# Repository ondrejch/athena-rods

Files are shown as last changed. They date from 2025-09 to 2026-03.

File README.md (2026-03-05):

# ATHENA-rods
Automated Teaching Hardware for Explaining Nuclear Absorption Rod(s)

ATHENA-rods is a hands-on teaching platform built around two Raspberry Pi 5 units and a small visualization app. It demonstrates how a reactor’s neutron population responds to control-rod motion using a real-time Point Kinetics Equation (PKE) simulation, live sensors, actuators, and simple displays.

- Instrument Box (RPi5): motor + servo moving a physical “control rod,” ultrasonic distance sensor, limit switch, and an 8×8 MAX7219 LED matrix. 
It also calibrates the ultrasonic ranging by adjusting the speed of sound using temperature and humidity from a DHT11 sensor.
- Control Box (RPi5): LCD1602 display, status LEDs, camera-based face recognition and RFID authorization.
- Visualization Box (any computer, or the Control Box): a Dash web app for live plots and sending control commands.

Most of the code is MIT-licensed unless otherwise noted.

---

## Repository layout

```
athena-rods/
├─ hardware/                         # 3D models (FreeCAD + STL) and assembly docs
│  ├─ arod_instrument/               # Instrument tower and slider mechanics
│  └─ arod_control/                  # Control box mounts (RFID, Camera+LCD)
├─ examples/                         # Small example scripts (RFID, face auth, instrument demos)
├─ src/
│  ├─ arod_instrument/               # Instrument Box runtime
│  │  ├─ instbox.py                  # Main loop: sensors, motor/servo, LED matrix, PKE
│  │  ├─ devices.py                  # GPIO bindings, Motor subclass (status/Condition)
│  │  ├─ matrixled.py                # LED matrix primitives
│  │  ├─ pke.py                      # ReactorPowerCalculator thread (real-time PKE)
│  │  └─ solver.py                   # General PKE solver (SciPy RK45)
│  ├─ arod_control/                  # Control Box runtime
│  │  ├─ ctrlbox.py                  # Main loop: auth, LCD, LEDs, sockets (hub)
│  │  ├─ authorization.py            # Face + RFID authorization
│  │  ├─ display.py, leds.py, LCD1602.py, hwsens.py
│  │  └─ socket_utils.py             # Socket helpers and StreamingPacket formats
│  ├─ arod_visual/
│  │  └─ visbox.py                   # Dash app for live plots and controls
│  └─ mfrc522/                       # Local MFRC522 driver (for RFID)
├─ setup_rpi.py                      # Packaging script for Raspberry Pi
├─ setup_vis.py                      # Packaging script for Visualization client
├─ build.sh                          # Build script for creating Debian packages
└─ LICENSE
```

Hardware build instructions and models:
- See hardware/README.md
- Camera + LCD bracket details: hardware/arod_control/Camera_LCD/README.md
- Assembly image: hardware/arod_instrument/assembly-main_components.png

---

## What it does

- Reads rod position with an ultrasonic sensor and converts it to reactivity.
- Calibrates ultrasonic distance in real time by computing the speed of sound from DHT11 temperature and humidity (or onboard RPi5 iio readings) and updating the sonar accordingly.
- Runs a real-time PKE simulation to compute neutron density.
- Streams telemetry (neutron density, reactivity, position, timestamp) to the Control/Visualization box.
- Displays motion and position on an 8×8 LED matrix; animates an “explosion” when power exceeds a threshold and resets the simulation.
- Enforces safety: limit switch stop, and a watchdog thread that prevents overextension.
- Operator authorization using face recognition and RFID.

---

## Hardware (summary)

Instrument Box (RPi5):
- Ultrasonic DistanceSensor: trigger BCM 23, echo BCM 24
- DHT11 temperature/humidity sensor for speed-of-sound calibration
- DC Motor (H-bridge): forward BCM 17, backward BCM 27, enable BCM 22
- Limit switch: Button on BCM 20 (immediate motor stop on press)
- Angular servo: BCM 15 (pulse widths set in code)
- MAX7219 8×8 LED matrix on SPI0 (rotate=1), low contrast

Control Box (RPi5):
- LCD1602 I2C display (auto-detect 0x27/0x3f)
- 3 status LEDs (GPIOs in src/arod_control/leds.py)
- RPi camera for face recognition
- MFRC522 RFID reader (SPI/I2C per driver variant)

Full hardware details and printable parts are in the hardware/ directory.

---

## Installation

### Using pip with extras (Recommended)

ATHENA-rods now uses a unified `setup.py` with extras for different environments:

#### For Raspberry Pi (Control & Instrument Boxes)

```bash
# Install with RPI-specific dependencies
pip install .[rpi]

# Or for development install
pip install -e .[rpi]
```

#### For the Visualization Box

```bash
# Install with visualization-specific dependencies  
pip install .[vis]

# Or for development install
pip install -e .[vis]
```

#### System Dependencies

**On Raspberry Pi**, you'll also need to install system packages:
```bash
sudo apt update
sudo apt install -y python3-pip python3-numpy python3-scipy python3-opencv \
    python3-gpiozero python3-smbus lm-sensors \
    libopenblas0 libatlas-base-dev libcap-dev
# For face_recognition (may require cmake, dlib, etc.)
# sudo apt install -y cmake build-essential
```

**Enable hardware interfaces** using `sudo raspi-config`:
- **Interface Options**: Enable SPI, I2C, and Camera.

#### requirements.txt for reproducible environments

For CI/HPC jobs and non-package workflows, use the pinned runtime dependency file:

```bash
pip install -r requirements.txt
```

Notes:
- `requirements.txt` includes both scientific core dependencies and optional RPi/visualization dependencies.
- For lean installs, prefer extras (`.[rpi]` or `.[vis]`) from `setup.py`.

### Using pre-built Debian packages

Pre-built Debian (`.deb`) packages are available from the [GitHub Releases page](https://github.com/ondrejch/athena-rods/releases).

#### For Raspberry Pi (Control & Instrument Boxes)

1.  Download the `python3-athena-rods-rpi_..._all.deb` file from the latest release.
2.  Install the package using `apt`, which will also handle system dependencies:
    ```bash
    # Example for version 0.2.0
    sudo apt install ./python3-athena-rods-rpi_0.2.0-1_all.deb
    ```

#### For the Visualization Box (Ubuntu/Debian `x86_64`)

1.  Download the `python3-athena-rods-vis_..._all.deb` file from the latest release.
2.  Install the package:
    ```bash
    # Example for version 0.2.0
    sudo apt install ./python3-athena-rods-vis_0.2.0-1_all.deb
    ```

### HPC / SLURM batch runs (solver-only workflows)

Hardware-dependent modules (`gpiozero`, camera, RFID) are not expected to run on HPC nodes.
For numerical studies, use `arod_instrument.solver` only.

Example SLURM script:

```bash
#!/bin/bash
#SBATCH --job-name=athena-pke
#SBATCH --time=00:05:00
#SBATCH --cpus-per-task=1
#SBATCH --mem=1G
#SBATCH --output=athena-pke-%j.out

module load python/3.12
python -m venv .venv
source .venv/bin/activate
pip install -r requirements.txt
PYTHONPATH=src python examples/pke/run_step_case.py examples/pke/input_step_reactivity.json
```

---

## Configuration

Socket endpoints are defined in `src/arod_control/__init__.py`:
- `CONTROL_IP`: IP address of the Control Box (hub/server).
- `PORT_STREAM` and `PORT_CTRL`: Stream and control TCP ports.
- `USE_SSL`: Set to `True` to enable SSL/TLS encryption for all sockets.

Other parameters:
- Instrument Box: `src/arod_instrument/instbox.py`
  - `MAX_ROD_DISTANCE` (default 17.0 cm)
  - `SOURCE_STRENGTH` for the external neutron source
  - Logging to `ATHENA_instrument.log`
  - `update_speed_of_sound` thread: uses `get_dht()` to read DHT11 temperature/humidity and sets `sonar.speed_of_sound`
- Control Box: `src/arod_control/ctrlbox.py`
  - `FAKE_FACE_AUTH` to bypass camera auth during development
  - `APPROVED_USER_NAMES` list
  - Logging to `ATHENA_controller.log`
- Visualization Box: `src/arod_visual/visbox.py`
  - Dash server default: http://127.0.0.1:8050, logs to `visbox.log`

Authorization assets:
- Face encodings pickle expected at `~/git/athena_rods/etc/face_rec_encodings.pickle`
- SSL certificates expected in `~/git/athena_rods/etc/certs/`
- MFRC522 storage and block map handled in `authorization.py`

---

## Authorization and Security

The system employs two layers of security: authorization for operators and encryption for network traffic.

### Operator Authorization (Face + RFID)

Two-factor authorization checks the user's identity via face scanning and the content of an RFID tag. This is implemented in `src/arod_control/authorization.py`. It uses a “something you have” (the RFID tag) tied to a secret derived from a CA certificate fingerprint. The design avoids storing plain tag IDs or shared secrets on the tag.

- **Fingerprint source**:
  - File: `~/git/athena_rods/etc/ca-chain.txt`
  - Content: a colon-separated hex fingerprint (e.g., from an X.509 CA certificate), parsed as a big-endian integer.

- **Deriving the tag’s expected data**:
  1) Read numeric `tag_id` from the MFRC522 reader.
  2) Compute `n = int(tag_id) × fp`, where `fp` is the CA fingerprint integer.
     - The code asserts there is no overflow: `n / fp == int(tag_id)`.
  3) Convert `n` to bytes (big-endian), hash with SHA3-512, and take the hex digest (128 hex chars).
  4) This 128-character hex digest is the “expected” content to be stored/read from the RFID tag.

- **Security properties**:
  - The secret (`fp`) never leaves the Control Box filesystem; tags only hold the digest.
  - Rotating the CA certificate (changing `fp`) invalidates all previously written tags. Re-provision tags by running `write_tag()` again with the new `fp`.
  - Keep `~/git/athena_rods/etc/ca-chain.txt` restricted (e.g., mode 600).

### Network Encryption (SSL/TLS)

All TCP socket communication between the Control Box, Instrument Box, and Visualization Box is encrypted using mutual SSL/TLS (mTLS). This ensures that data is secure and that only authorized clients can connect to the control hub.

- **How it works**:
  - The Control Box acts as the TLS server.
  - The Instrument Box and Visualization Box act as TLS clients.
  - The server requires and verifies a client certificate, and clients verify the server's certificate against a shared Certificate Authority (CA).
  - This is enabled by default via the `USE_SSL = True` flag in `src/arod_control/__init__.py`.

- **Certificate Generation**:
  - A helper script, `generate_ssl_certs.py`, is provided to create the necessary X.509 certificates.
  - This script must be run once to generate:
    - `ca.crt`: The Certificate Authority certificate.
    - `server.crt` & `server.key`: For the Control Box (server).
    - `instbox.crt` & `instbox.key`: For the Instrument Box client.
    - `visbox.crt` & `visbox.key`: For the Visualization Box client.
  - These certificates are placed in `~/git/athena_rods/etc/certs/`.

- **Client Certificate Loading**:
  - The client-side `SocketManager` automatically loads the correct certificate (`instbox.crt` or `visbox.crt`) based on the handshake string provided during initialization (e.g., `stream_instr` for the instrument box).
  
---

## Running

In three terminals/devices:

1) Control Box (RPi5, the hub)
```bash
python3 -m arod_control.ctrlbox
```

2) Instrument Box (RPi5, mechanics + PKE)
```bash
python3 -m arod_instrument.instbox
```

3) Visualization (same machine or laptop)
```bash
python3 -m arod_visual.visbox
# then open http://127.0.0.1:8050
```

---

## Controls and telemetry

Control messages (JSON, line-delimited over ctrl socket):
```json
{
  "type": "settings",
  "motor_set": 1,  // 1=up, 0=stop, -1=down
  "servo_set": 1,  // 1=engage, 0=scram
  "source_set": 1  // 1=external neutron source ON, 0=OFF
}
```

Streamed telemetry (binary) uses `StreamingPacket.pack_triplet_plus_time64`:
- 3 × float32: neutron_density, rho, distance
- 1 × float64: timestamp (milliseconds since epoch)
- Big-endian, total 20 bytes

---

## Internals (high-level)

Instrument Box (instbox.py) threads:
- `update_speed_of_sound`: samples DHT11 temperature/humidity and sets sonar speed of sound
- `ctrl_receiver`: reads JSON from Control Box and enqueues
- `process_ctrl_status`: applies motor/servo/source settings
- `rod_protection`: polls position and stops motor if distance ≥ `MAX_ROD_DISTANCE` while moving up
- `ReactorPowerCalculator`: real-time PKE integration
  - Sets `explosion_event` if power > threshold and resets state
- `stream_sender`: periodically sends latest neutron/rho/position/timestamp
- `matrix_led_driver`: shows arrows/height bar; runs explosion rectangle animation when `explosion_event` is set

Key synchronization:
- `stop_event`: global shutdown for all threads
- `update_event`: signals new PKE data to `stream_sender`
- `explosion_event`: signals the LED animation and PKE reset

Motor status notifications:
- `Motor` subclass (`devices.Motor`) uses a `threading.Condition` to publish status changes.
- `wait_for_status_change(stop_event, timeout)` returns when status changes or when the timeout expires.

Safety:
- Immediate `motor.stop()` on limit switch press
- Independent `rod_protection` watchdog
- Clean shutdown paths for sockets and threads

---

## Examples

- `examples/face_auth`: scripts to capture faces and train encodings
- `examples/arod_control/rfid_read.py`: RFID basics
- `examples/arod_instrument`: stand-alone LED matrix and DHT demos
- `examples/mfrc522`: read/write/dump tag examples
- `examples/pke/input_step_reactivity.json`: solver input case for batch/CI validation
- `examples/pke/run_step_case.py`: runs the JSON case and prints a deterministic summary
- `examples/pke/expected_output_step_reactivity.txt`: expected output for quick regression checks

Run examples directly with `python3` from the repository root.

Reproducibility check:

```bash
PYTHONPATH=src python3 examples/pke/run_step_case.py examples/pke/input_step_reactivity.json
```

---

## Development

Editable install:
```bash
pip3 install -e .
```

Run tests:
```bash
pytest -v
```

Generate a revision/version manifest (for reports and archived runs):
```bash
PYTHONPATH=src python3 util/write_revision_manifest.py --context ci
```

Run control-performance tests (step-response metrics):
```bash
PYTHONPATH=src python3 util/run_control_performance_tests.py \
  --report build/control_performance_report.json
```

Run network/security performance benchmarks (TCP vs mTLS on loopback):
```bash
PYTHONPATH=src python3 util/run_network_security_performance.py \
  --report build/network_security_performance_report.json
```

Run security verification tests (mTLS acceptance/rejection behavior):
```bash
PYTHONPATH=src python3 util/run_security_verification_tests.py \
  --report build/security_verification_report.json
```

Logging:
- Instrument: `ATHENA_instrument.log` (in `src/arod_instrument/`)
- Control: `ATHENA_controller.log`
- Visual: `visbox.log`

Contributions welcome:
- Keep code thread-safe (prefer Events/Conditions over long sleeps).
- Make timeouts interruptible with `stop_event.wait()`.
- Add clear logging and comments.

---

## License

MIT License (unless otherwise indicated in individual files).
See LICENSE.

## Acknowledgments:
- gpiozero, luma.led_matrix, NumPy, SciPy, Dash/Plotly, and MFRC522 libraries

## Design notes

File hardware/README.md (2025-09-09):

# Hardware to build ATHENA-rod

Below is the list of parts used in the original build.
* 2x [RaspberryPi 5 kits](https://www.amazon.com/RasTech-Raspberry-Active-Cooler-Readers/dp/B0D2WYFS23/) - Control and Instrument boxes
* 1x [Starter parts kit](https://www.amazon.com/SunFounder-Ultimate-Raspberry-Detailed-Tutorials/dp/B09BMVT4CB/) - sensors, servo, displays, etc.
* 2x [6V 5RPM motor](https://www.amazon.com/FOCMKEAS-6V-5RPM-Gearboxes-handicrafts/dp/B0F7X5G4RN/) - moves the control rod
* A 3D printer, e.g. [Ender-3 S1](https://www.amazon.com/Official-Creality-Extruder-Leveling-220%C3%97220%C3%97270mm/dp/B0F9FDN25Y/r) 
* Screws (M2 mostly), wires, a [simple multimeter](https://www.amazon.com/AstroAI-Multimeter-Auto-Ranging-Resistance-Non-Contact/dp/B08DHHJPS1/), basic workshop tools, ..

# 3D printed components
The structural components are 3D printed in PLA+ using Ender S1. 
This directory contains both FreeCAD models and STL meshes exported from FreeCAD.

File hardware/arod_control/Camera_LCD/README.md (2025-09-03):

# Camera stand with LCD display

The camera stem and back cover is taken from https://www.printables.com/model/38043-raspberry-pi-camera-stand (made in Fusion 3D). You can get the F3D files there if you wish, I just printed the STLs. 

The display-stand replaces original the stand, and was made in FreeeCAD.

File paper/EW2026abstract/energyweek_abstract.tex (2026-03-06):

\documentclass[11pt]{article}
\usepackage[letterpaper,margin=1in]{geometry}
\usepackage[T1]{fontenc}
\usepackage{lmodern}
\usepackage{microtype}

\setlength{\parindent}{0pt}
\setlength{\parskip}{6pt}

\begin{document}

\textbf{Title:} ATHENA-rods: A Low-Cost Cyber-Physical Platform for Nuclear Control Education and Secure Digital I\&C Prototyping

\textbf{Authors:} Ondrej Chvala

\textbf{Email:} ochvala@utexas.edu

\textbf{Key findings:} A home-fabricable, approximately \$390 platform built from two Raspberry Pi 5 nodes and 3D-printed hardware can integrate reactor kinetics, physical actuation, and X.509-based secure communications for interdisciplinary engineering training.

Digital instrumentation and control (I\&C) modernization in nuclear systems requires engineers who can work across reactor dynamics, hardware integration, and cybersecurity. At the same time, there is a persistent gap between modern network-security capabilities and commonly deployed SCADA/OT practice, and educational infrastructure that makes this gap tangible is limited. ATHENA-rods addresses this need with an open-source cyber-physical platform for interdisciplinary training. This work is part of the ongoing nuclear digital twins effort at The University of Texas at Austin.

The platform is organized as three cooperating nodes: an instrument node (\texttt{instbox}), a control node (\texttt{ctrlbox}), and a visualization node (\texttt{visbox}). The instrument node uses a DC motor, servo, ultrasonic ranging, DHT11 environmental sensing, a limit switch, and an LED matrix to emulate control-rod motion and reactor-state feedback via real-time point kinetics. The control node manages authorization and command routing; the visualization node provides live telemetry and supervisory controls. Security is integrated through X.509 certificate management and TLS/mTLS communication, with optional face-plus-RFID operator authorization. Mechanical components are distributed as FreeCAD and STL assets for consumer FDM printing.

Current validation includes reproducibility manifests, control-performance metrics, and security verification workflows. Representative step-response tests show stable positive and negative reactivity transients with overshoot of approximately 9.0\% and 4.0\%, respectively. Estimated build cost is approximately \$390. Ongoing work includes hardware-backed latency/throughput benchmarking, certificate lifecycle testing, and DNP3/TLS integration. Code, CAD, and test artifacts are available on GitHub (https://github.com/ondrejch/athena-rods).

\end{document}

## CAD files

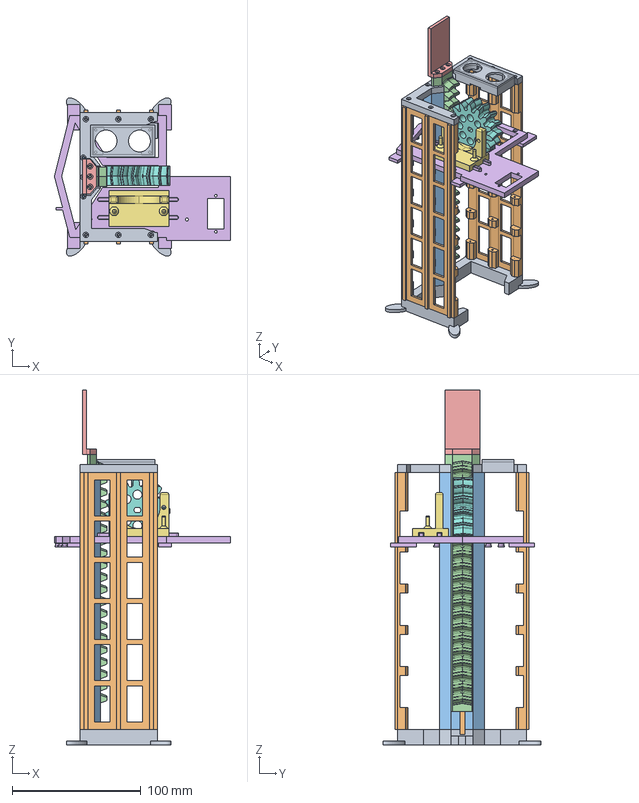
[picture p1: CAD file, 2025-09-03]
hardware/arod_instrument/assembly.FCStd
137.0 x 123.0 x 276.0 mm
bottom-stand-02_001
side-stand-02_001
slider-01_001
rack-01_001
upper-rail-02_001
middle-bracket-03_001
wagon-slider-02_001
pinion-01_001
top-stand-02_001
bottom-pin-01_001

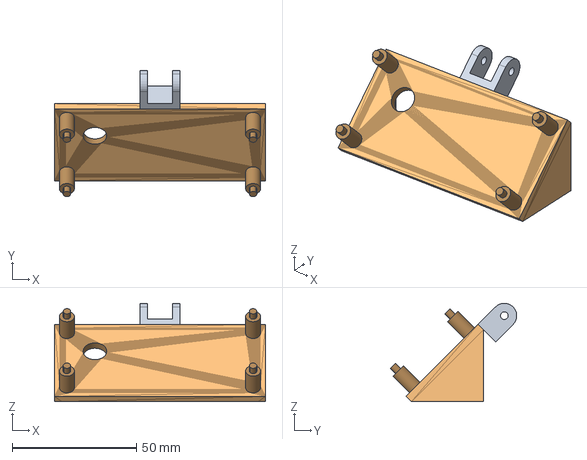
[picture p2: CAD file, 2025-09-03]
hardware/arod_control/Camera_LCD/FreeCAD/display-stand.FCStd
85.0 x 50.9 x 39.6 mm
BaseFeature

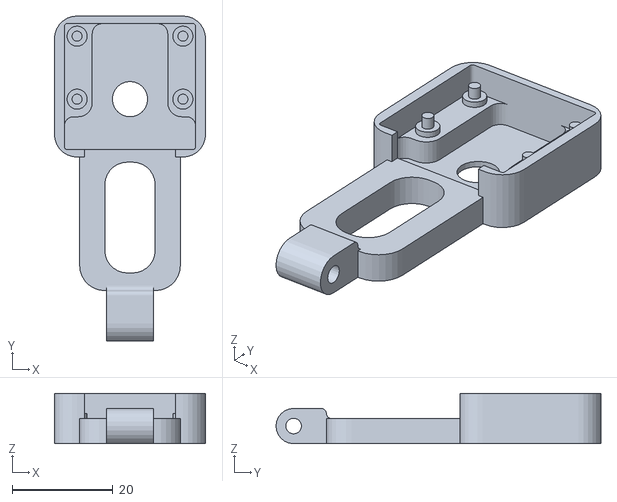
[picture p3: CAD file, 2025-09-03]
hardware/arod_control/Camera_LCD/STL/camera_front_box_v003.stl
30.0 x 64.5 x 10.0

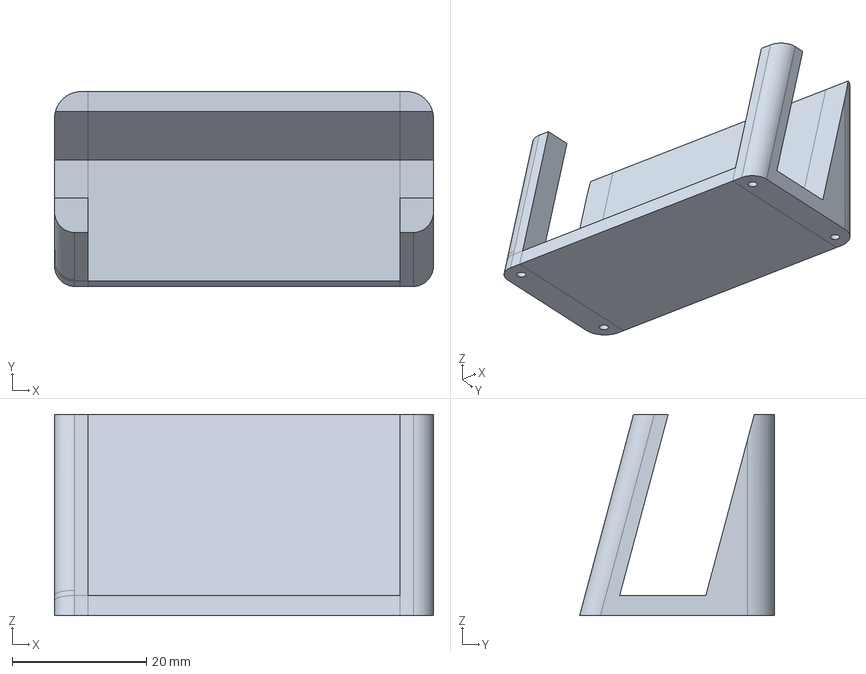
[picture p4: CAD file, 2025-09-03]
hardware/arod_control/RFID/FreeCAD/stand.FCStd
56.5 x 29.1 x 30.0 mm

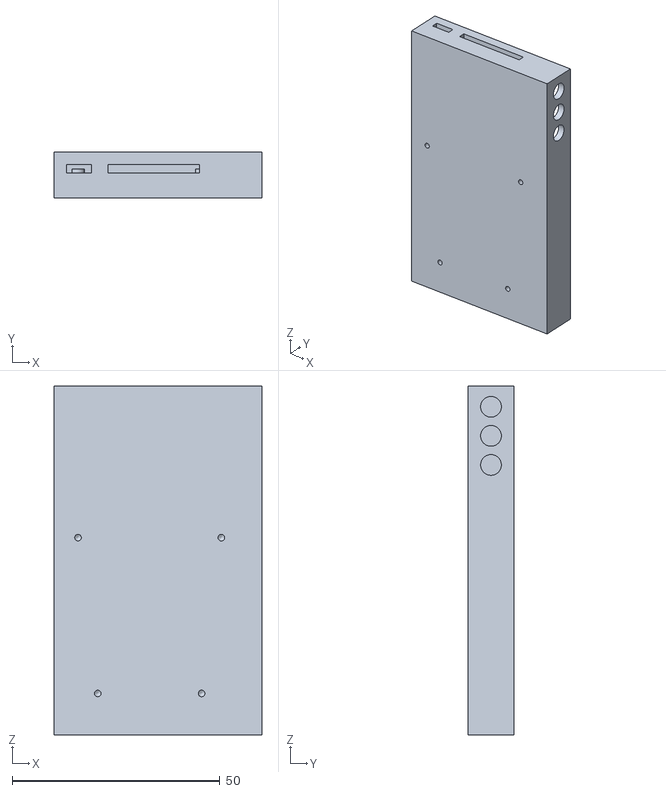
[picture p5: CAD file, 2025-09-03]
hardware/arod_control/RFID/STL/back-01-Body.stl
50.0 x 11.0 x 84.0

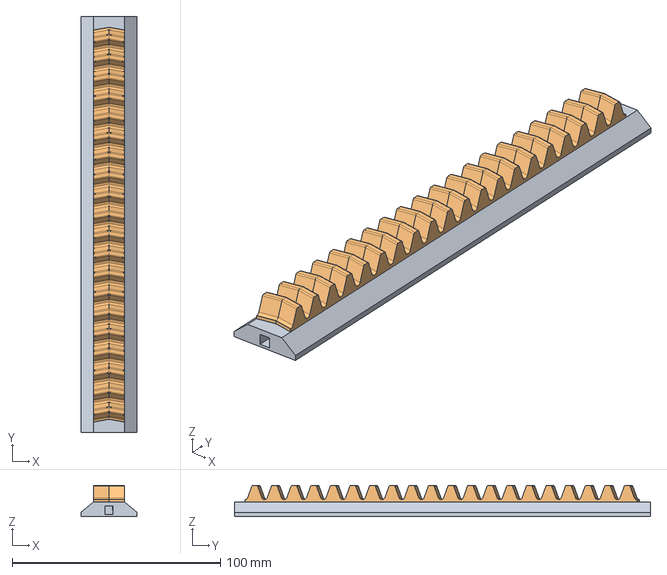
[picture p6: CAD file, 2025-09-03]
hardware/arod_instrument/ControlRod/FreeCAD/rack-01.FCStd
27.0 x 200.0 x 15.0 mm
InvoluteRack

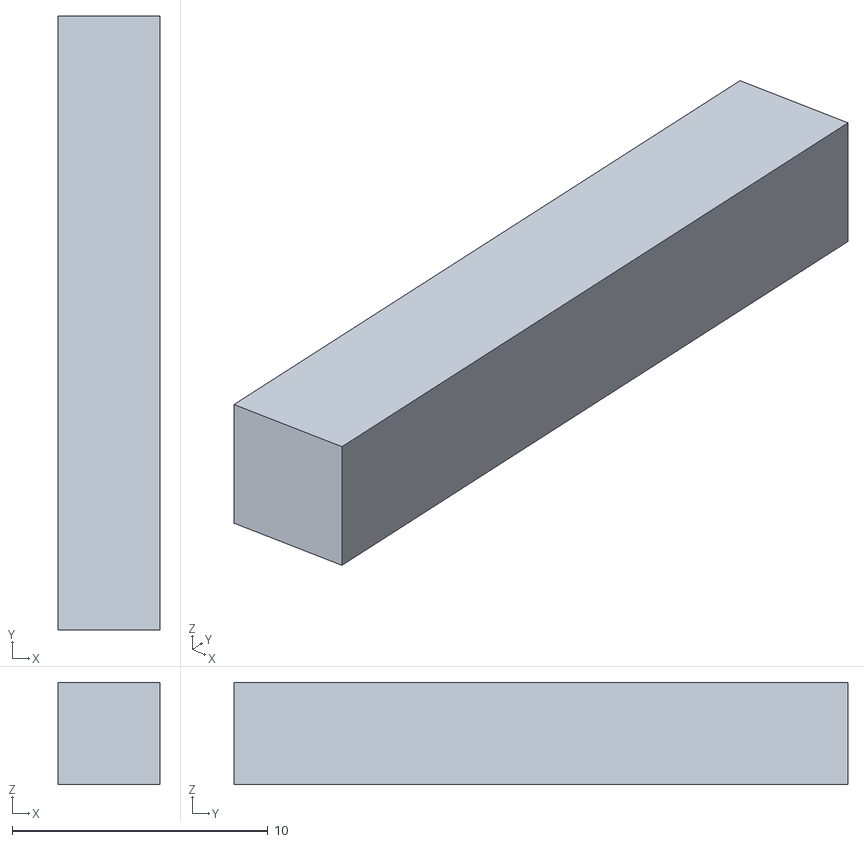
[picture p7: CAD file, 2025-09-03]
hardware/arod_instrument/ControlRod/STL/bottom-pin-01-Part.stl
4.00 x 24.0 x 4.00

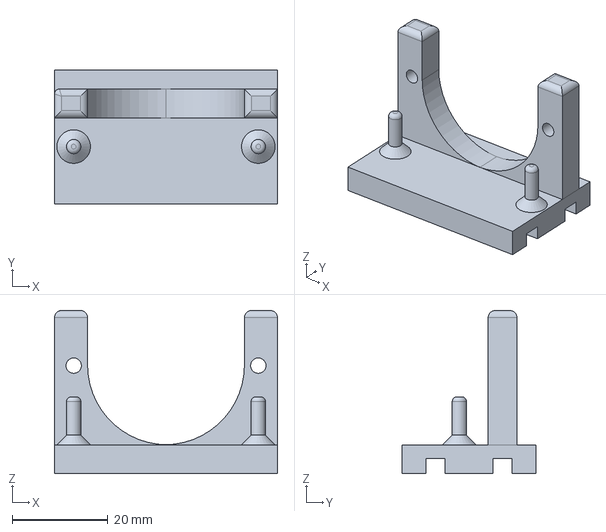
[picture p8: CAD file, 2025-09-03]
hardware/arod_instrument/Slider/FreeCAD/wagon-slider-02.FCStd
46.5 x 28.0 x 34.0 mm

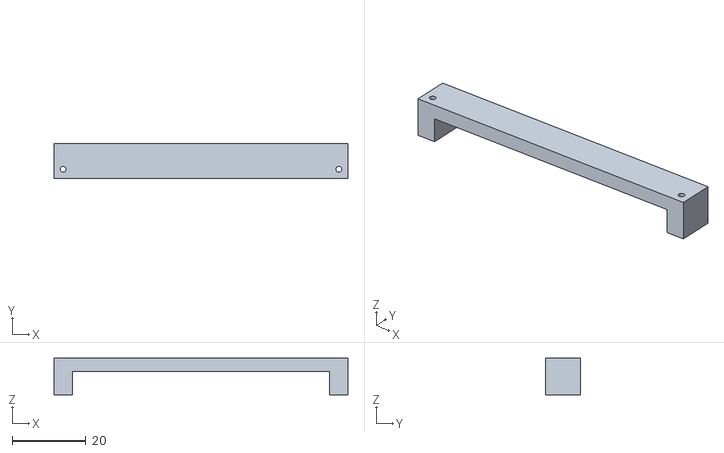
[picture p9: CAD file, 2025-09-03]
hardware/arod_instrument/Slider/STL/clamp-02-Part.stl
80.0 x 9.50 x 10.0

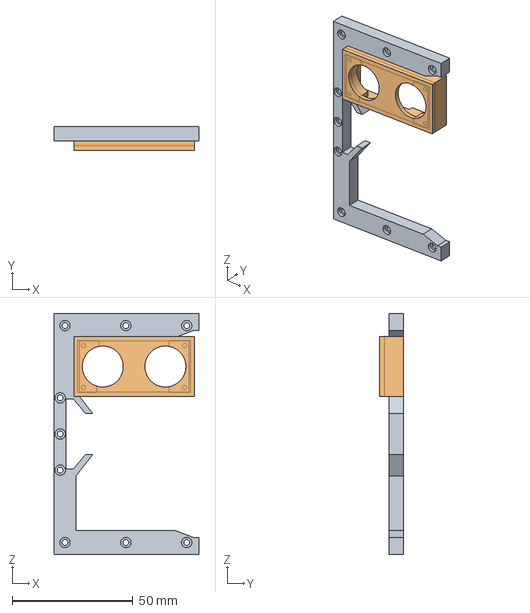
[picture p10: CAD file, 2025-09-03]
hardware/arod_instrument/Tower/FreeCAD/top-stand-02.FCStd
60.0 x 10.0 x 100.0 mm

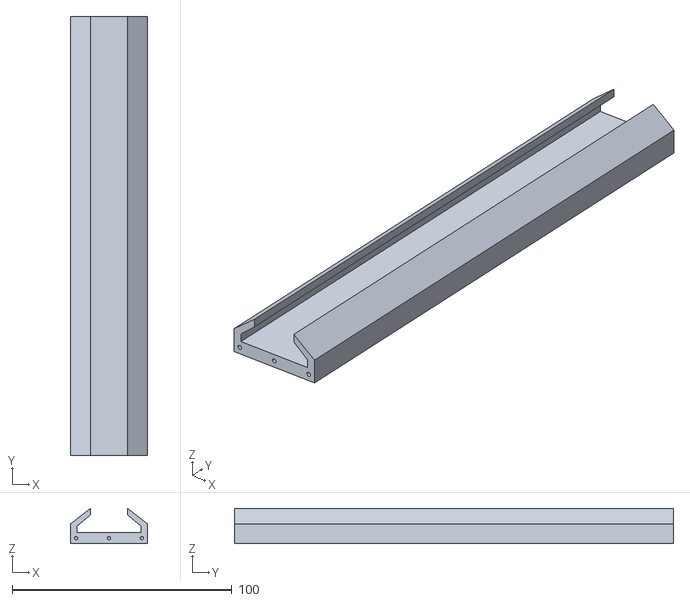
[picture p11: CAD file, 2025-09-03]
hardware/arod_instrument/Tower/STL/slider-01-Part.stl
35.0 x 200.0 x 16.0

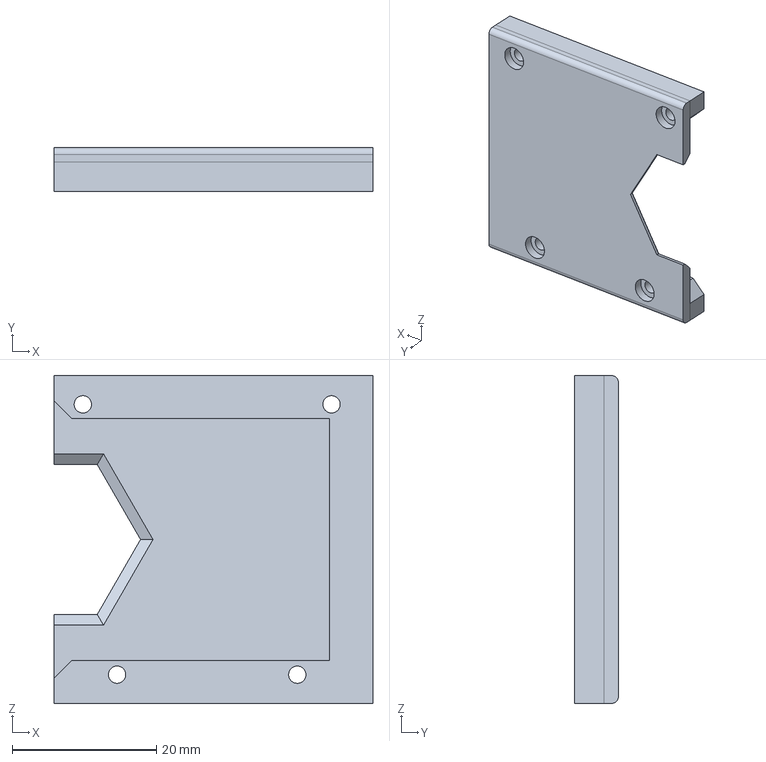
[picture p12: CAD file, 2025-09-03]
hardware/arod_control/RFID/FreeCAD/token_pocket.FCStd
44.3 x 6.10 x 45.5 mm

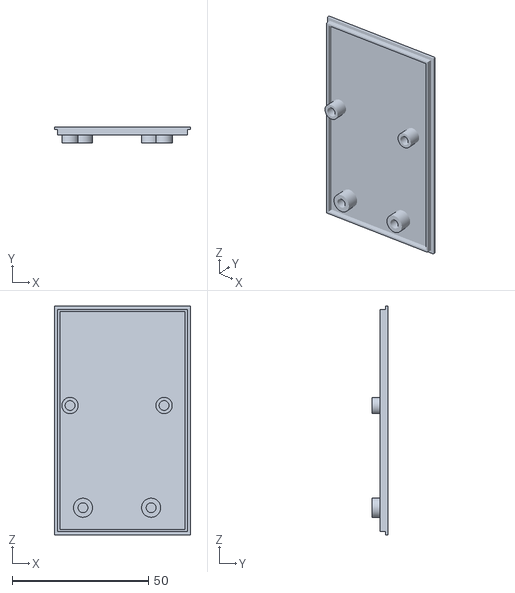
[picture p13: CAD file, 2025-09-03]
hardware/arod_control/RFID/STL/front-01-Part.stl
50.0 x 6.00 x 84.0

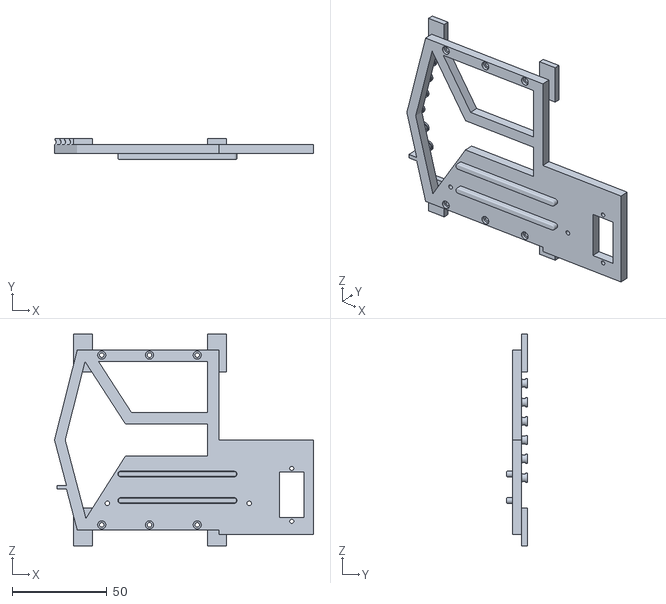
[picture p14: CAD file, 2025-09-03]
hardware/arod_instrument/Slider/STL/middle-bracket-03-Part.stl
137.0 x 11.0 x 112.0

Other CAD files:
hardware/arod_control/Camera_LCD/STL/display-stand-Part.stl
hardware/arod_instrument/ControlRod/FreeCAD/bottom-pin-01.FCStd
hardware/arod_instrument/ControlRod/STL/rack-01-Part.stl
hardware/arod_instrument/Slider/FreeCAD/clamp-02.FCStd
hardware/arod_control/Camera_LCD/STL/camera_back_cover_v002.stl
hardware/arod_control/RFID/FreeCAD/back-01.FCStd
hardware/arod_control/RFID/FreeCAD/front-01.FCStd
hardware/arod_control/RFID/STL/stand-Part.stl
hardware/arod_control/RFID/STL/token_pocket-Body (Mirror #1).stl
hardware/arod_instrument/ControlRod/FreeCAD/pinion-01.FCStd
hardware/arod_instrument/ControlRod/FreeCAD/upper-rail-02.FCStd
hardware/arod_instrument/ControlRod/STL/pinion-01-Part.stl
hardware/arod_instrument/ControlRod/STL/upper-rail-02-Part.stl
hardware/arod_instrument/Slider/FreeCAD/middle-bracket-03.FCStd
hardware/arod_instrument/Slider/STL/wagon-slider-02-Part.stl
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

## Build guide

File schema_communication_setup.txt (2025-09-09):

┌─────────────────────────────────────────────────────────────────┐
│                         INSTBOX (RPi5)                          │
│                                                                 │
│  ┌───────────────────┐      ┌───────────────────────────────┐   │
│  │ Hardware          │      │ PKE Simulation                │   │
│  │ - Ultrasonic      │──┬───│ - ReactorPowerCalculator      │   │
│  │ - Motor/Servo     │  │   │ - Neutron density calculation │   │
│  │ - DHT11 sensor    │  │   │ - Reactivity computation      │   │
│  │ - Limit switch    │  │   └───────────────────────────────┘   │
│  │ - LED Matrix      │  │                                       │
│  └───────────────────┘  │                                       │
│                         ▼                                       │
│  ┌───────────────────────────────────────────────────────┐      │
│  │ Socket Communications                                 │      │
│  │ - stream_socket (telemetry) & ctrl_socket (commands)  │      │
│  └─────────────────┬─────────────────────────────────────┘      │
│                    │                          ▲                 │
└────────────────────│──────────────────────────│─────────────────┘
                     │                          │
                     │  TCP/IP                  │  TCP/IP
                     ▼                          │
┌─────────────────────────────────────────────────────────────────┐
│                          CTRLBOX (RPi5)                         │
│                                                                 │
│  ┌───────────────────────────┐     ┌──────────────────────┐     │
│  │ Authorization             │     │ Hardware             │     │
│  │ - Face recognition        │     │ - LCD Display        │     │
│  │ - RFID authentication     │     │ - Status LEDs        │     │
│  └───────────────────────────┘     └──────────────────────┘     │
│                    │                              ▲             │
│                    │                              │             │
│                    ▼                              │             │
│  ┌──────────────────────────────────────────────────────────┐   │
│  │ Socket Server Hub                                        │   │
│  │ ┌─────────────────┐              ┌────────────────────┐  │   │
│  │ │ Stream Server   │              │ Control Server     │  │   │
│  │ │ (PORT_STREAM)   │              │ (PORT_CTRL)        │  │   │
│  │ └─────────────────┘              └────────────────────┘  │   │
│  │          │                                   ▲           │   │
│  └──────────┼───────────────────────────────────┼───────────┘   │
│             │                                   │               │
└─────────────┼───────────────────────────────────┼───────────────┘
              │                                   │
              │  TCP/IP                           │  TCP/IP
              ▼                                   │
┌─────────────────────────────────────────────────────────────────┐
│                          VISBOX                                 │
│                                                                 │
│  ┌───────────────────────────────┐  ┌──────────────────────┐    │
│  │ Socket Connections            │  │ User Interface       │    │
│  │ - stream_socket (telemetry)   │◄─┤ - Live plots         │    │
│  │ - ctrl_socket (commands)      │─►┤ - Control sliders    │    │
│  └───────────────────────────────┘  │ - Status indicators  │    │
│                                     └──────────────────────┘    │
└─────────────────────────────────────────────────────────────────┘

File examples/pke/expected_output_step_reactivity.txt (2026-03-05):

description: Half-dollar positive step reactivity insertion
final_time_s: 20.000000
initial_neutron_density: 1.000000
final_neutron_density: 77.553956
peak_neutron_density: 77.553956

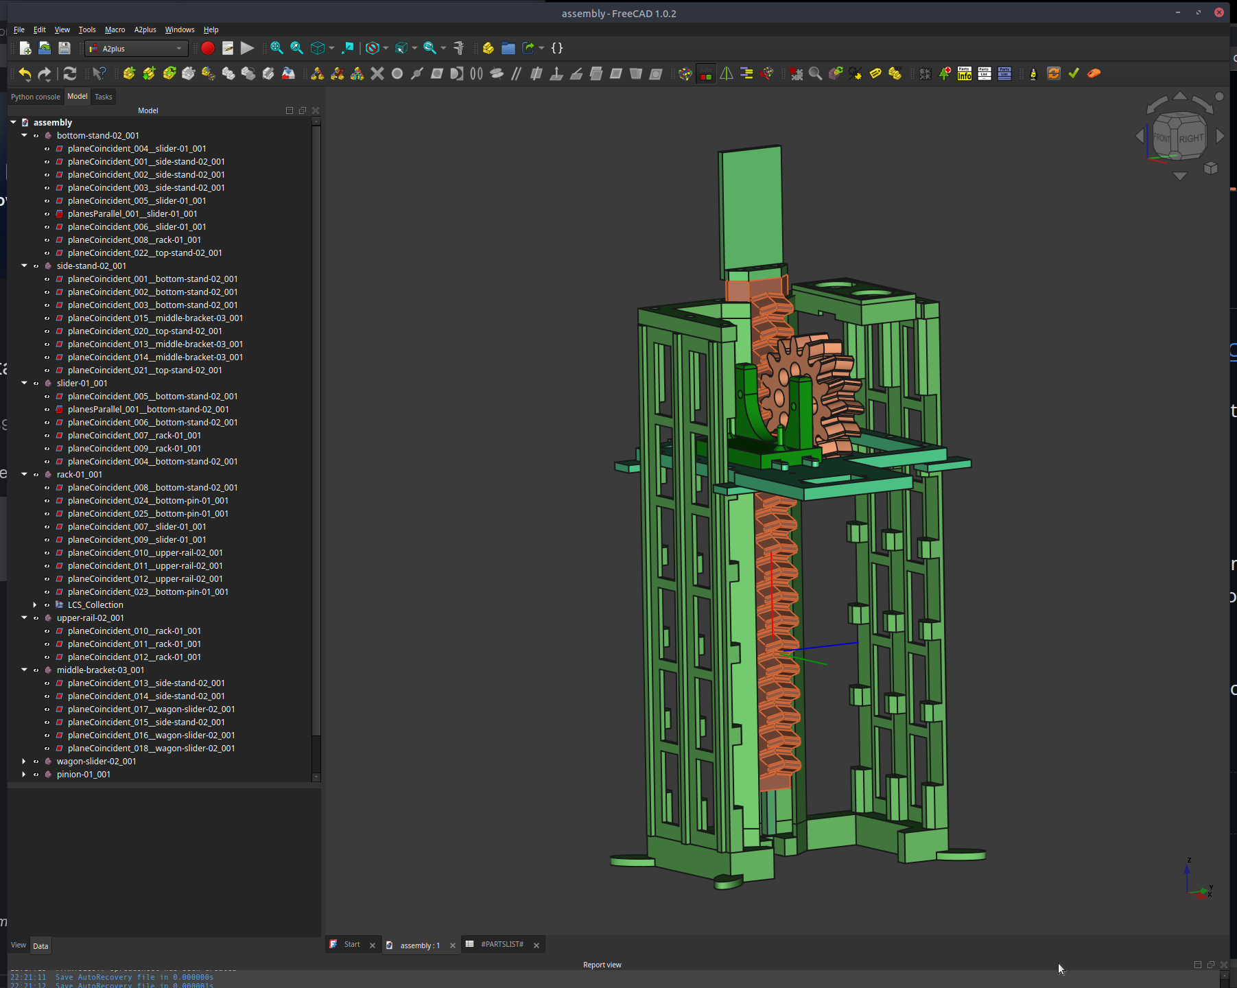
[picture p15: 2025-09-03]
hardware/arod_instrument/assembly-main_components.png

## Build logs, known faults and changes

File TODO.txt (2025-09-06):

* Use https://github.com/gpiozero/gpiozero for GPIO
* Replace time.sleep() with threading.Event.wait()
* Add passwords to RFID tags, see MIFARE Classic standard

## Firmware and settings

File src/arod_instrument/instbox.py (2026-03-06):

#!/usr/bin/env python3
"""
Main loop for the instrumentation box RPi5
Ondrej Chvala <ochvala@utexas.edu>
"""

from typing import Any, Dict
import logging
import queue
import time
import threading
import os
from arod_control import PORT_CTRL, PORT_STREAM, CONTROL_IP
from arod_instrument.devices import (
    get_dht,
    get_distance,
    speed_of_sound,
    motor,
    sonar,
    rod_engage,
    rod_scram,
    limit_switch,
)
from arod_instrument.pke import ReactorPowerCalculator
from arod_control.socket_utils import SocketManager, StreamingPacket
from arod_control import USE_SSL, AUTH_ETC_PATH

# Where the SSL certificates are
CERT_DIR: str = os.path.join(os.path.expanduser("~"), AUTH_ETC_PATH, "certs")

# External source for PKE
SOURCE_STRENGTH: float = 5.0  # Default external neutron source strength when enabled

# Limit on rod extension, 17 cm
MAX_ROD_DISTANCE: float = 17.0

# LOGGER
logging.basicConfig(level=logging.DEBUG, format='%(asctime)s - %(name)s - %(levelname)s - %(message)s',
                    handlers=[logging.FileHandler("ATHENA_instrument.log"), logging.StreamHandler()])
logger = logging.getLogger('AIBox')  # ATHENA rods Instrumentation Box

# Initialize socket connections with SSL support
stream_socket = SocketManager(
    CONTROL_IP, PORT_STREAM, "stream_instr",
    use_ssl=USE_SSL, cert_dir=CERT_DIR
)
ctrl_socket = SocketManager(
    CONTROL_IP, PORT_CTRL, "ctrl_instr",
    use_ssl=USE_SSL, cert_dir=CERT_DIR
)

# Communication queues
ctrl_status_q: queue.Queue[Dict[str, Any]] = queue.Queue(maxsize=100)  # Limit size to prevent memory issues
stop_event: threading.Event = threading.Event()
current: threading.Thread = threading.current_thread()


def limit_switch_pressed() -> None:
    """Handler for when limit switch is pressed"""
    motor.stop()
    switch_msg = {"type": "limit_switch", "value": "pressed"}
    ctrl_socket.send_json(switch_msg)
    logger.info("Limit switch pressed, motor stopped")


def limit_switch_released() -> None:
    """Handler for when limit switch is released"""
    switch_msg: Dict[str, str] = {"type": "limit_switch", "value": "released"}
    ctrl_socket.send_json(switch_msg)
    logger.info("Limit switch released")


# Set up switch callbacks
limit_switch.when_pressed = limit_switch_pressed
limit_switch.when_released = limit_switch_released


def rod_protection(cr_reactivity: 'Reactivity') -> None:
    """ Continuously checks rod distance and stops motor if overextended """
    while not stop_event.is_set():
        try:
            distance = cr_reactivity.distance
            # Poll the sonar for latest value
            if hasattr(cr_reactivity, 'get_reactivity'):
                cr_reactivity.get_reactivity()
                distance = cr_reactivity.distance
            if distance >= MAX_ROD_DISTANCE:
                if motor.status == 1:  # Only stop if trying to extend further
                    motor.stop()
                    logger.warning(f"Rod overextended! Motor stopped at {distance:.2f} cm.")
            stop_event.wait(timeout=0.1)  # Poll every 100ms, interruptible
        except Exception as e:
            logger.error(f"Error in rod_protection: {e}")
            stop_event.wait(timeout=1)


def process_ctrl_status() -> None:
    """Process control messages from the queue"""
    while not stop_event.is_set():
        try:
            # Try to get a message with timeout
            ctrl_status = ctrl_status_q.get(timeout=1)
            logger.info(f"Processing control message: {ctrl_status}")

            # Handle different message types
            if 'type' in ctrl_status:
                message_type = ctrl_status.get('type')

                if message_type == 'settings':
                    # Process settings message
                    motor_set = ctrl_status.get('motor_set', 0)
                    servo_set = ctrl_status.get('servo_set', 0)
                    source_set = ctrl_status.get('source_set', 0)

                    logger.info(f"Received settings: motor={motor_set}, servo={servo_set}, source={source_set}")

                    if motor_set == 1:
                        if limit_switch.is_pressed:
                            rod_lift()
                        motor.up()
                    elif motor_set == -1:
                        if not limit_switch.is_pressed:
                            motor.down()
                    else:
                        motor.stop()

                    if servo_set == 1:
                        rod_engage()
                    else:
                        rod_scram()

                    if 'power_calculator' in globals():
                        if source_set == 1:
                            # Enable external neutron source
                            power_calculator.set_source(SOURCE_STRENGTH)
                            logger.info(f"External neutron source enabled with strength {SOURCE_STRENGTH}")
                        else:
                            # Disable external neutron source
                            power_calculator.set_source(0.0)
                            logger.info("External neutron source disabled")

            # Mark task as done
            ctrl_status_q.task_done()

        except queue.Empty:
            # No messages in queue, just continue
            pass
        except Exception as e:
            logger.error(f"Error processing control status: {e}")

        time.sleep(0.01)


def rod_lift() -> None:
    """ Temporarily overwrites limit switch to lift the rod reliably """
    try:
        rod_engage()
        original_callback = limit_switch.when_pressed
        limit_switch.when_pressed = None
        motor.up()
        time.sleep(0.7)
        motor.stop()
        limit_switch.when_pressed = original_callback
        logger.info(f"Rod lifted successfully: {limit_switch.is_pressed}")
    except Exception as e:
        logger.error(f"Error during rod_lift: {e}")
        motor.stop()  # Safety stop
        limit_switch.when_pressed = limit_switch_pressed  # Restore callback


class Reactivity:
    """ Control rod reactivity class """
    def __init__(self) -> None:
        super().__init__()
        self.cr_min: float = 5.0  # Rod minimum controlled position [cm]
        self.cr_max: float = 15.0  # Rod maximum controlled position [cm]
        self.delta_rho: float = 800.0e-5  # Range of reactivity covered, 800 pcm by default
        self.cr_pos = get_distance  # CR position from sonar
        self.distance: float = -999.9  # Current CR position [cm], the single source of truth
        assert self.cr_min < self.cr_max

    @property
    def cr_zero_rho(self) -> float:
        """Returns CR position at zero reactivity"""
        return (self.cr_min + self.cr_max) / 2.0

    @property
    def cr_delta(self) -> float:
        """Return the control rod range"""
        return self.cr_max - self.cr_min

    def get_reactivity(self) -> float:
        """Reads sonar distance, updates the internal state, and turns it into reactivity"""
        try:
            # This method now updates the authoritative state
            self.distance = self.cr_pos()
            return (self.distance - self.cr_zero_rho) * self.delta_rho / self.cr_delta
        except Exception as e:
            logger.error(f"Error getting reactivity: {e}")
            self.distance = -999.9 # Ensure distance is reset on error
            return 0.0  # Safe default


def set_speed_of_sound() -> bool:
    """Update sonar speed of sound using the latest temperature/humidity sample."""
    my_speed_of_sound: float = -999.9
    retry_count = 0
    max_retries = 10

    while my_speed_of_sound < 0 and retry_count < max_retries:
        try:
            tempC, humid_pct = get_dht()
            if tempC > -273.15 and humid_pct >= 0.0:
                logger.info(f'Temperature: {tempC:.2f} C, Humidity: {humid_pct:.2f} %')
                my_speed_of_sound = speed_of_sound(tempC, humid_pct)
                sonar.speed_of_sound = my_speed_of_sound
                logger.info(f'Speed of sound set to {my_speed_of_sound}')
                return True
        except Exception as e:
            logger.warning(f"Error setting speed of sound: {e}")
            retry_count += 1

        stop_event.wait(timeout=1)

    if retry_count >= max_retries:
        logger.error("Failed to set speed of sound after multiple attempts")
        return False

    return True


def update_speed_of_sound(wait: float = 10 * 60) -> None:
    """Periodically update the speed of sound based on temperature and humidity"""
    while not stop_event.is_set():
        try:
            success = set_speed_of_sound()
            if success:     # Wait for the specified time before next update
                stop_event.wait(timeout=wait)
            else:           # If failed, retry sooner
                stop_event.wait(timeout=60)
        except Exception as e:
            logger.error(f"Error in update_speed_of_sound: {e}")
            stop_event.wait(timeout=60)


def ctrl_receiver() -> None:
    """Receive and process control messages"""
    while not stop_event.is_set():
        try:
            # Receive a complete JSON message
            data, success = ctrl_socket.receive_json()

            if success:
                if data:  # Only process if we have actual data
                    # logger.debug(f"Received control data: {data}")
                    # Put in queue for processing by main thread
                    try:
                        ctrl_status_q.put_nowait(data)
                    except queue.Full:
                        # Make room by removing oldest item
                        try:
                            ctrl_status_q.get_nowait()
                            ctrl_status_q.put_nowait(data)
                        except (queue.Empty, queue.Full):
                            logger.warning("Control queue management error")
                # Don't wait if we had a successful read, even without data
                # This allows more responsive processing of partial messages
                time.sleep(0.01)
            else:
                # Connection issue, wait longer before retry
                stop_event.wait(timeout=1)

        except Exception as e:
            logger.error(f"Control receiver error: {e}")
            stop_event.wait(timeout=1)


def stream_sender(cr_reactivity: Reactivity, update_event: threading.Event) -> None:
    """Send stream data to control box"""
    global power_calculator
    counter: int = 0
    while not stop_event.is_set():
        try:
            # Wait for signal that new data is available
            update_event.wait(timeout=1.0)

            if update_event.is_set():
                # Get current values
                neutron_density = power_calculator.current_neutron_density
                rho = power_calculator.current_rho
                # Access distance directly from the reactivity object
                distance = cr_reactivity.distance
                ts_ms = time.time() * 1000.0  # milliseconds since epoch (float64)

                if counter % 10 == 0:
                    logger.info(f"CR pos: {distance:4.1f} cm, rho: {1e5*rho:.0f} pcm, N: {neutron_density:.2e}, t: {ts_ms:.1f} ms")
                counter += 1

                # Pack and send the data (3x float32 + 1x float64 timestamp in ms)
                data = StreamingPacket.pack_triplet_plus_time64(neutron_density, rho, distance, ts_ms)
                success = stream_socket.send_binary(data)

                if not success:
                    logger.warning("Failed to send stream data, will retry")

                # Reset the event for next update
                update_event.clear()

        except Exception as e:
            logger.error(f"Stream sender error: {e}")
            stop_event.wait(timeout=1)


def matrix_led_driver(cr_reactivity: Reactivity, explosion_event: threading.Event) -> None:
    """ Driver for matrix LED display; both motor and stop_event are global scope """
    from matrixled import arrowUp, arrowDown, notMoving, displayRectangle
    from matrixled import startUp as matrix_led_start_up
    from matrixled import ledsOff as matrix_led_shut_down
    logger.info("Matrix LED display thread started")
    h_min: float = 3.0
    h_max: float = MAX_ROD_DISTANCE
    dh: float = h_max - h_min
    matrix_led_start_up()

    while not stop_event.is_set():
        # Check for explosion event first, with a short timeout
        if explosion_event.wait(timeout=0.01):
            logger.info("Explosion event triggered, showing animation.")
            for i in range(1, 5):
                if stop_event.is_set(): break
                displayRectangle(i, do_fill=True)
                stop_event.wait(0.2)
            for i in range(1, 5):
                if stop_event.is_set(): break
                displayRectangle(i, do_fill=False)
                stop_event.wait(0.2)

            if not stop_event.is_set():
                explosion_event.clear()  # Reset the event

        if stop_event.is_set():  # If the wait was interrupted by the stop_event, exit the loop
            break

        new_status = motor.status
        old_status = new_status

        pic_jiggle: int = 0  # Offsets the arrow pictures to indicate movement
        while old_status == new_status and not explosion_event.is_set():
            # logger.debug(f'motor status:  {new_status}')
            ih: int = int(7.0 * (cr_reactivity.distance - h_min) / dh)
            if ih < 0:
                ih = 0
            if ih > 8:
                ih = 8
            if motor.status == 0:
                notMoving(pic_jiggle, ih)
            elif motor.status == -1:
                arrowDown(pic_jiggle, ih)
            elif motor.status == 1:
                arrowUp(pic_jiggle, ih)
            else:
                logger.error(f"Motor status: {motor.status}")

            stop_event.wait(timeout=0.2)
            if stop_event.is_set():  # If the wait was interrupted by the stop_event, exit the loop
                break

            if pic_jiggle == 0:
                pic_jiggle = 1
            else:
                pic_jiggle = 0
            new_status = motor.status

    matrix_led_shut_down()


def main() -> None:
    """Main function that initializes all components and starts threads"""
    # Start speed of sound update thread
    threading.Thread(target=update_speed_of_sound, daemon=True).start()

    # Initialize socket connections with retries
    stream_socket.connect_with_backoff()
    ctrl_socket.connect_with_backoff()
    logger.info(f"Stream socket connected: {stream_socket.connected}")
    logger.info(f"Control socket connected: {ctrl_socket.connected}")

    # Start control message receiver
    threading.Thread(target=ctrl_receiver, daemon=True).start()

    # Initialize reactivity calculation - this object now holds the state
    cr_reactivity = Reactivity()
    update_event = threading.Event()
    explosion_event = threading.Event()

    # Start matrix LED thread
    threading.Thread(target=matrix_led_driver, args=(cr_reactivity, explosion_event), daemon=True).start()

    # Start power calculator
    global power_calculator
    power_calculator = ReactorPowerCalculator(cr_reactivity.get_reactivity, dt=0.05, update_event=update_event, explosion_event=explosion_event)
    power_calculator.start()

    # Start rod protection thread
    threading.Thread(target=rod_protection, args=(cr_reactivity,), daemon=True).start()

    # Start control message processor, passing the state-holding object
    threading.Thread(target=process_ctrl_status, daemon=True).start()

    # Start stream sender, passing the state-holding object
    threading.Thread(target=stream_sender, args=(cr_reactivity, update_event), daemon=True).start()

    logger.info("All threads started, entering main loop")

    # Main loop - could implement additional monitoring or management here
    try:
        while not stop_event.is_set():
            stop_event.wait(timeout=5.0)
    except KeyboardInterrupt:
        logger.info(f"Threads: {threading.active_count()}\nKeyboard interrupt detected, shutting down...")
        return


if __name__ == "__main__":
    logger.info("Instrumentation computer started.")
    try:
        main()
    except KeyboardInterrupt:
        stop_event.set()
        logger.info("Shutting down on keyboard interrupt...")
    except Exception as e:
        stop_event.set()
        logger.error(f"Unhandled exception in main: {e}")
    finally:
        # Clean shutdown
        logger.info("Closing sockets and cleaning up...")
        stop_event.set()

        global power_calculator
        # Safely stop power calculator
        if 'power_calculator' in globals() and power_calculator is not None:
            try:
                power_calculator.stop()  # Don't call join() - could deadlock if thread is stuck
            except Exception as e:
                logger.warning(f"Error stopping power calculator: {e}")

        time.sleep(0.1)  # wait a little
        # Close sockets with some timeout protection
        try:
            stream_socket.close()
        except Exception as e:
            logger.warning(f"Error closing stream socket: {e}")

        try:
            ctrl_socket.close()
        except Exception as e:
            logger.warning(f"Error closing ctrl socket: {e}")

        logger.info("Shutdown complete.")

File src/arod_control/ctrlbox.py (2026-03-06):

#!/usr/bin/env python3
"""
Main loop for the control box RPi5
Ondrej Chvala <ochvala@utexas.edu>
"""

from typing import Dict, Any, Optional, List
import logging
import threading
import time
import socket
import json
import os
import ssl
import queue
import signal
from arod_control.leds import LEDs
from arod_control.display import Display
from arod_control.authorization import RFID_Authorization, FaceAuthorization
from arod_control import USE_SSL, AUTH_ETC_PATH, PORT_CTRL, PORT_STREAM  # Socket settings
from arod_control.socket_utils import StreamingPacket  # For packet size (now 4 floats)
from arod_control import speak

CERT_DIR: str = os.path.join(os.path.expanduser("~"), AUTH_ETC_PATH, "certs")  # Where the SSL certificates are
FAKE_FACE_AUTH: bool = True  # FAKE face authorization, use for development only!!
CB_STATE: Dict[str, Any] = {  # Control box machine state
    'auth': {       # Authorization status
        'face': '',
        'rfid': '',
        'disp': False   # Is display computer allowed to connect?
    },
    'refresh': {    # Refresh rate for loops [s]
        'leds':  1,     # LED
        'display': 1,   # LCD
        'rfid': 15*60,  # RFID authorization
        'as_1': 0.1     #
    },
    'leds': [9, 9, 9],  # 0 - off, 1 - on, 9 - flashing
    'message': {
        'text': '',     # Text to show
        'timer': 2      # for how long [s]
    },
    'controls': {
        'motor_set': 0,
        'servo_set': 1,
        'source_set': 0,
    }
}

APPROVED_USER_NAMES: list[str] = ['Ondrej Chvala']

# LOGGER
logging.basicConfig(level=logging.DEBUG, format='%(asctime)s - %(name)s - %(levelname)s - %(message)s',
                    handlers=[logging.FileHandler("ATHENA_controller.log"), logging.StreamHandler()])
logger = logging.getLogger('ACBox')  # ATHENA rods Control Box

# SOCKET communications setup
connections: Dict[str, Any] = {
    "stream_instr": None,
    "stream_display": [],  # Changed to list
    "ctrl_instr": None,
    "ctrl_display": []     # Changed to list
}
connection_lock: threading.Lock = threading.Lock()
servers: Dict[str, Any] = {
    "stream": None,
    "ctrl": None
}
stop_event: threading.Event = threading.Event()  # Global event for clean shutdown
ctrl_speak_q: queue.Queue[Dict[str, Any]] = queue.Queue(maxsize=10) # Queue for speaker thread


def request_shutdown(reason: Optional[str] = None) -> None:
    """Request cooperative shutdown for all running threads."""
    if reason:
        logger.info(reason)
    stop_event.set()


def _safe_close_socket(sock: Any, label: str) -> None:
    """Best-effort socket close helper used during shutdown."""
    if sock is None:
        return
    try:
        sock.shutdown(socket.SHUT_RDWR)
    except Exception:
        pass
    try:
        sock.close()
    except Exception as e:
        logger.warning(f"Error closing {label}: {e}")


def close_server_sockets() -> None:
    """Close listener sockets to stop accept loops."""
    for server_name, server_info in list(servers.items()):
        if not server_info:
            continue
        server = server_info["socket"] if isinstance(server_info, dict) else server_info
        _safe_close_socket(server, f"{server_name} server socket")
        servers[server_name] = None
        logger.info(f"{server_name} server socket closed")


def close_client_connections() -> None:
    """Close all active instrument/display client sockets."""
    with connection_lock:
        for conn_name, conns in list(connections.items()):
            if isinstance(conns, list):
                for conn in list(conns):
                    _safe_close_socket(conn, f"{conn_name} client socket")
                conns.clear()
            else:
                _safe_close_socket(conns, f"{conn_name} socket")
                connections[conn_name] = None
    logger.info("All connections closed.")


def install_signal_handlers() -> None:
    """Install SIGINT/SIGTERM handlers for service-mode graceful shutdown."""
    def _handle_signal(signum: int, _frame: Any) -> None:
        signal_name = signal.Signals(signum).name
        request_shutdown(f"Signal {signal_name} received, shutting down...")

    for sig in (signal.SIGINT, signal.SIGTERM):
        signal.signal(sig, _handle_signal)


def accept_stream_connections() -> None:
    """Accept connections on the stream server and route them based on handshake"""
    server_info = servers["stream"]
    server = server_info["socket"] if isinstance(server_info, dict) else server_info
    ssl_context = server_info.get("context") if isinstance(server_info, dict) else None

    server.settimeout(1.0)

    while not stop_event.is_set():
        try:
            conn, addr = server.accept()
            logger.info(f"Incoming stream connection from {addr}")

            # Wrap socket with SSL if enabled
            if ssl_context:
                try:
                    conn = ssl_context.wrap_socket(conn, server_side=True)
                    logger.info(f"SSL handshake completed with {addr} - Cipher: {conn.cipher()}")
                    # Can also access: conn.getpeercert() to get client cert details
                except ssl.SSLError as ssl_err:
                    logger.error(f"SSL handshake failed with {addr}: {ssl_err}")
                    conn.close()
                    continue

            conn.settimeout(10.0)

            logger.info(f"Incoming stream connection from {addr}")

            handshake_data = conn.recv(128)
            if not handshake_data:
                logger.warning(f"Empty handshake from {addr}, closing connection")
                conn.close()
                continue

            try:
                handshake = handshake_data.decode('utf-8').strip()
                if handshake.endswith('\n'):
                    handshake = handshake[:-1]
            except UnicodeDecodeError:
                logger.warning(f"Invalid handshake encoding from {addr}, closing connection")
                conn.close()
                continue

            valid = {"stream_instr", "stream_display"}
            if handshake not in valid:
                logger.warning(f"Invalid stream handshake '{handshake}' from {addr}, expected one of {sorted(valid)}")
                conn.close()
                continue

            if handshake == "stream_display" and not CB_STATE['auth']['disp']:
                logger.info(f"Rejected {handshake} connection from {addr} due to AUTH=False")
                conn.close()
                continue
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

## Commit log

2025-09-03 structural component models
    [assembly.FCStd, back-01-Body.stl, back-01.FCStd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]
2025-09-05 motor management
2025-09-06 limit switch handling
2025-09-06 rod extension limit
2025-09-07 matrix led
2025-09-07 rod extension protection thread
2025-09-07 matrix led progress
2025-09-07 motor speed
2025-09-09 Add hardware abstraction layer tests (MFRC522, SimpleMFRC522, LCD1602, LEDs, hwsens)
2025-09-09 Fix test isolation issue in test_hwsens.py using function-scoped pytest fixtures
    [test_hwsens.py]
2025-09-09 Implement comprehensive hardware mocking and fix test isolation issues
    [test_hwsens.py]
2025-10-08 Implement power state variable in PKEFuchsNordheimSolver
    - Added fission_energy and nu parameters to thermal_default_params and fast_reactor_params
    - Updated PKEFuchsNordheimSolver.__init__ to read new parameters
    - Modified solve method to include P in state vector [n, P, C1, ..., CN, T]
    - Updated initial conditions so P0 = n0 * (fission_energy / nu)
    - Updated ODE equations: dPdt = (fission_energy / nu) * (n * prompt + delayed)
    - Updated temperature equation: dTdt = P / m_Cp
    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
